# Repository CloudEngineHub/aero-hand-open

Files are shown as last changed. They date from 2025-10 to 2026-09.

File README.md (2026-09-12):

Aero Hand Overview

<p align="center">
  
  
  
  <!-- <a href="https://github.com/chestnut-robotics/aero-hand-open/issues"><img src="https://img.shields.io/github/issues/chestnut-robotics/aero-hand-open?color=yellow" alt="Issues"></a> -->
  
  
  
  
  
  
</p>

Aero Hand Open is an **open-source**, **tendon-driven** robotic hand designed and developed by Chestnut Robotics (formerly TetherIA) for dexterous manipulation research. Unlike expensive proprietary solutions, this hand focuses on **simplicity**, **reliability**, and **accessibility** by using standard 3D printing and off-the-shelf electronic components.

Each joint is optimized for mechanical efficiency through tendon actuation, enabling smooth and natural motion while maintaining a **lightweight** and **compact** design, making it perfect for research labs, educational institutions, and robotics enthusiasts who need an **affordable** yet **capable** manipulation platform.

> **📄 Paper:** [Aero Hand Open: A Simulation-Ready Tendon-Driven Hand for Dexterous Manipulation Learning](https://arxiv.org/abs/2608.28578) (arXiv:2608.28578)   
> **📚 Learn More:** https://chestnut-robotics.github.io/aero-hand-open/   
> **🛒 Shop:** https://shop.tetheria.ai/

# Aero Hand Open features
- 7 DoFs robotic hand with 5 fingers (16 joints in total)
- Tendon-driven architecture for smooth and natural motion
- Fully 3D-printed structure, modular and easy to assemble
- Lightweight design — **389 g**
- Affordable — complete kit for **$314 USD**
- Open-source hardware and firmware
- Independent Python SDK, and compatible with ESP32 and ROS2 systems

# Table of Contents
- [Aero Hand Open features](#aero-hand-open-features)
- [Overview](#overview)
- [Resources](#resources)
  - [Bill of Materials (BOM)](#bill-of-materials-bom)
  - [CAD Files and 3D Models](#cad-files-and-3d-models)
  - [Assembly Guide](#assembly-guide)
  - [PCB Design](#pcb-design)
  - [Hardware Setup](#hardware-setup)
  - [Software SDK](#software-sdk)
  - [ROS2 and Teleoperation](#ros2-and-teleoperation)
  - [Simulation](#simulation)
  - [Reinforcement Learning](#reinforcement-learning-tools)
- [Getting help](#Getting-help)
- [Citation](#citation)
- [License — TL;DR](#license--tldr)
- [Disclaimer](#disclaimer)
- [Project Updates & Community](#project-updates--community)
  - [Updates History](#updates-history)
  - [FAQ](#faq)
  - [Contact](#contact)

# Overview

Overview1

Overview1

Overview1

Overview1

Overview1

Overview1

Overview1

# Resources
## Bill of Materials (BOM)
The complete list of components required to build Aero Hand Open can be found here:

 [👉 Aero Hand Open – Bill of Materials](./hardware/Assembly/BOM.csv)

This document includes all mechanical, electronic, and printed parts — such as motors, tendons, bearings, fasteners, and 3D-printed components.

Each item is listed with its part number, vendor, quantity, and estimated cost to help you easily source or substitute parts.

## CAD Files and 3D Models
STEP files and one click print files can be found here:

[👉 Aero Hand Open – CAD](./hardware/CAD/).

[👉 Aero Hand Open – Onshape Link](https://cad.onshape.com/documents/afc7e0ca7eb6d412ec8771f8/w/bc4d7e45e17e23d622d2bad2/e/c711982b7882da925263fb55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)

All parts are printed on a Bambu X1C, 0.4mm nozzle, 0.2mm layer height, tree support enabled, select support on build plate only checkbox. We recommend keeping the same print orientation and settings. The print orientation will minimize supports and optimize surface tolerances/smoothness for interfacing components.

## Assembly Guide
The step-by-step assembly instructions for Aero Hand Open are provided in the following document:

[👉 Aero Hand Open – Assembly Guide](https://docs.tetheria.ai/docs/assembly)

This guide covers the entire build process, from mounting the actuators to routing the tendons and connecting the electronics. Each finger module can be assembled independently and attached to the palm afterward, allowing easier maintenance and quick replacement.

## PCB Design
All design files - including Gerber files, KiCad project files, BOM, and CPL - are available in [PCB folder](./hardware/PCB/).

Referring to [PCB doc](https://docs.tetheria.ai/docs/pcb) for more technical details.

## Hardware Setup

Please refer to [hardware_setup](https://docs.tetheria.ai/docs/hardware_setup) doc 

## Software SDK
Please refer to [`sdk/README.md`](sdk/README.md) and [sdk](https://docs.tetheria.ai/docs/sdk) doc

### Sequencing Demo
The Sequencing Demo demonstrates how different finger motions can be combined into continuous, pre-defined sequences.

This script enables users to perform complex gestures — such as pinching, opening the palm, or making a peace sign — by automatically coordinating joint movements in a timed sequence.

You can find the example code in the SDK example folder. 

👉 [`sdk/examples/`](sdk/examples)

Once the SDK is installed and the serial port has been configured, you can run any of the example scripts directly using Python as follows:

```bash
python run_sequence.py
```
[🎥 Watch the demo](assets/sequence_square.mp4)

## ROS2 and Teleoperation
The Aero Hand Open integrates seamlessly with ROS2 **humble** for advanced robotics applications.

Refer to the [ROS2](https://docs.tetheria.ai/docs/ros2) doc and [`ros2/`](./ros2/) folder for complete setup instructions and source code.

## Simulation

We provide high-fidelity simulation models for the **Aero Hand Open**.

**Currently Supported**
- **MuJoCo**

Support for additional simulation platforms is under active development and will be released in future updates.  
Refer to the [RL and Sim](https://docs.tetheria.ai/docs/hand_sim) documentation and the [`sim_rl/simulation/`](./sim_rl/simulation/) directory for detailed explanations and model files.

## Reinforcement Learning Tools

We offer reinforcement learning tools built on top of state-of-the-art frameworks such as **mujoco_playground**, enabling users to train custom policies for the Aero Hand Open with minimal effort.

Refer to the [RL and Sim](https://docs.tetheria.ai/docs/hand_sim) documentation and the [`sim_rl/mujoco_playground/`](./sim_rl/mujoco_playground/) directory for full setup instructions and training procedures.  
An example of deploying trained policies in ROS is also provided in the [`ros2/`](./ros2/) directory.

# Getting help

**GitHub Issues** – Bugs + feature requests only.

**GitHub Discussions** –
- Build / electronics / mechanical help
- SDK / ROS2 / sim/RL "how do I…"
- Design proposals and feedback

**Discord** –
- Quick questions, live debugging, voice/screen‑share
- Social chat, lab intros, "I printed my first hand!"
- Live events and office hours

# Citation

If you use Aero Hand Open in your research, please cite our paper:

> Nan Wang, Mohit Yadav, Jonathan Wulff, Aidan Rosenbaum, Kezhou Chen, Yuvan Sharma, Xu Dong, Yiwei Tao.
> **Aero Hand Open: A Simulation-Ready Tendon-Driven Hand for Dexterous Manipulation Learning.** arXiv:2608.28578, 2026.
> [📄 arXiv](https://arxiv.org/abs/2608.28578) · [PDF](https://arxiv.org/pdf/2608.28578)

```bibtex
@article{wang2026aerohandopen,
  title   = {Aero Hand Open: A Simulation-Ready Tendon-Driven Hand for Dexterous Manipulation Learning},
  author  = {Wang, Nan and Yadav, Mohit and Wulff, Jonathan and Rosenbaum, Aidan and
             Chen, Kezhou and Sharma, Yuvan and Dong, Xu and Tao, Yiwei},
  journal = {arXiv preprint arXiv:2608.28578},
  year    = {2026},
  url     = {https://arxiv.org/abs/2608.28578}
}
```

# License — TL;DR



- You **can** integrate Aero Hand units you purchase from Chestnut Robotics into **commercial robots and products** you sell.
- **Software (firmware & SDK):** Apache-2.0 — commercial use OK (with notices).
- **Design files (CAD/STEP/STL, drawings, BOM, docs):** CC BY‑NC‑SA 4.0 — **non‑commercial** only; derivatives must use the same license with attribution.
- Want to **manufacture/print parts** or **make your own hands** from our design files for commercial use (spares, kits, or clones)? → **Commercial manufacturing license required**.
- **Commercial licensing & volume buys:** see **LICENSE.md** (or email us at contact@chestnut.bot).

See [**LICENSE.md**](LICENSE.md) for definitions, examples, and contact details.

© 2025 Chestnut Robotics, Inc. (formerly TetherIA, Inc.) All rights reserved.

# Disclaimer
Aero Hand Open is an open-source research prototype intended for educational and experimental purposes only.

While every effort has been made to ensure build accuracy and functionality, this design has not been validated for prolonged or heavy-duty use.

Users should exercise caution when assembling, operating, or modifying this device. Chestnut Robotics, Inc. and its contributors shall not be held liable for any personal injury, property damage, or other losses resulting from the use, misuse, or modification of this design. By using this project, you acknowledge and accept full responsibility for any associated risks.

Important Notes:
- 3D-printed parts may exhibit tolerance variations depending on printer and material settings.
- The tendon-driven mechanism requires regular tension adjustment to maintain consistent motion.
- Overloading the joints or applying excessive torque may cause mechanical deformation or servo damage.
- This project is provided as is, without any warranty or guarantee of fitness for a particular purpose.

We encourage the community to share improvements, feedback, and modifications through pull requests or GitHub discussions.

Your contributions will help make Aero Hand Open more reliable and versatile for the entire robotics community.

# Project Updates & Community
## Updates History
See [RELEASE_NOTES.md](RELEASE_NOTES.md) for details.

## FAQ
Q1: Can I modify and redistribute the Aero Hand Open design?

A: Yes, as long as it complies with the CC BY-NC-SA 4.0 license (non-commercial, attribution required, share alike).

Q2: What 3D printer and material do you recommend?

A: Any FDM printer with a ≥200×200 mm bed. PLA works best for strength and dimensional accuracy.

More questions please refer to our [online documentation](https://docs.tetheria.ai/docs/hardware_faq) 

## Contact
For questions, feedback, or collaboration inquiries, please reach out to us through the following channels:

 🛒 Shop: [Aero Hand Open – Chestnut Robotics Store](https://shop.tetheria.ai/) 

 📚 Docs: [Aero Hand Open Docs](https://docs.tetheria.ai/)

 📧 Email: support@chestnut.bot

 🌐 Website: [chestnut.bot](https://chestnut.bot)

 🐙 GitHub: [chestnut-robotics](https://github.com/chestnut-robotics)

 💬 Discord: [Chestnut Robotics Discord](http://discord.gg/ZQKWK7NebQ)

  🐦 X/Twitter: [Chestnut Robotics on X](https://x.com/ChestnutRobotic)

  📺 YouTube: [Chestnut Robotics on YouTube](https://www.youtube.com/@TetherIA_ai)

  💼 LinkedIn: [Chestnut Robotics on LinkedIn](https://www.linkedin.com/company/tetheria/)

We welcome discussions, contributions, and new ideas from the community.

If you have improvements to the design, firmware, or control software, feel free to open a Pull Request or start a Discussion on GitHub.

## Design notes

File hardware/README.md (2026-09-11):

**License:** [CC BY-NC-SA 4.0](https://creativecommons.org/licenses/by-nc-sa/4.0/) © 2025 Chestnut Robotics

[**Mechanical**](https://docs.tetheria.ai/docs/mechanical)

[**Assembly**](https://docs.tetheria.ai/docs/assembly)

[**Hardware Setup**](https://docs.tetheria.ai/docs/hardware_setup)

[**PCB**](https://docs.tetheria.ai/docs/pcb)

[**Firmware**](https://docs.tetheria.ai/docs/firmware)

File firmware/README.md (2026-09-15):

<p align="center">
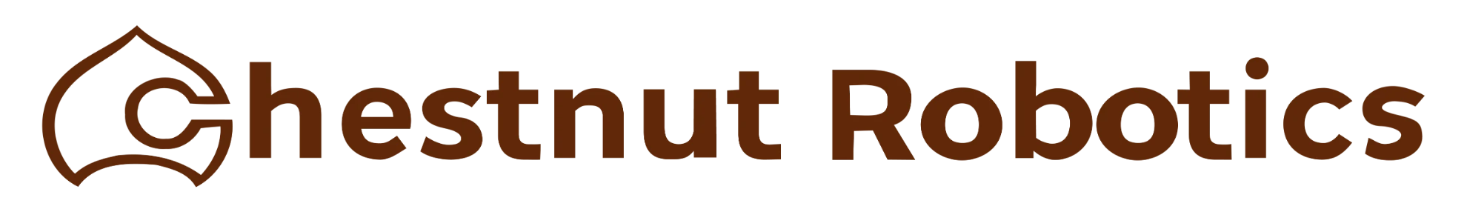
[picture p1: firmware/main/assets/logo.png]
Aero Hand Open by Chestnut Robotics
  
  <br/><br/>
</p>

# Aero Hand Open Firmware v0.1.0 — README

A reference guide for building, flashing, using, and extending the **Aero Hand Open** firmware that runs on an ESP32‑S3 (Seeed Studio XIAO ESP32S3) and drives Feetech smart servos - Feetech HLS3606M.

**Note:** If you do not need advanced control over the actuator, you only need the `.bin` file from this repository. You can download the bin files from the `main/bin` folder , and use the GUI to upload them to your device. We recommend using the [aero-open-sdk](https://github.com/chestnut-robotics/aero-hand-open/tree/main/sdk) to upload the firmware by running the `aero-open-gui`.

---

## Table of Contents
- [1) Overview](#1-overview)
- [2) Repository Layout](#2-repository-layout)
- [3) Hardware & Software Requirements](#3-hardware--software-requirements)
- [4) Quick Start](#4-quick-start)
- [5) Firmware Architecture](#5-firmware-architecture)
- [6) Selecting LEFT vs RIGHT Hand at Build Time](#6-selecting-left-vs-right-hand-at-build-time)
- [7) Serial Protocol](#7-serial-protocol)
- [8) Homing Behavior](#8-homing-behavior)
- [9) Extending the Firmware with a New Command](#9-extending-the-firmware-with-a-new-command)
- [10) Code Reference (quick lookup)](#10-code-reference-quick-lookup)
- [11) Safety & Best Practices](#11-safety--best-practices)
- [12) Troubleshooting](#12-troubleshooting)
- [13) Contribution](#13-contribution)
- [14) License](#14-license)
- [15) Support](#15-Support)

---

## 1) Overview

The firmware exposes a compact **fixed 16‑byte binary serial protocol** so a host PC can command finger positions and query telemetry while the device handles **homing**, calibration, and basic safety on‑board.

**Major components**
- **`firmware_v0.1.0.ino`** — Main sketch: hardware init, serial command parser, periodic tasks, and command handlers.
- **`HandConfig.h`** — **Defines LEFT_HAND or RIGHT_HAND** (build‑time) to select the correct baseline calibration and channel directions.
- **`Homing.h` / `Homing.cpp`** — Implements the **homing** routine (`HOMING_start()` / `HOMING_isBusy()`), plus baseline tables and helpers.

**Servos / channels** (7):
1. Thumb CMC Abduction
2. Thumb CMC Flexion
3. Thumb Tendon (thumb curl/tendon drive)
4. Index
5. Middle
6. Ring
7. Pinky

---

## 2) Repository Layout

```
/main
  ├─ firmware_v0.1.0.ino          # main sketch
  ├─ HandConfig.h                 # LEFT_HAND / RIGHT_HAND selection
  ├─ Homing.h                     # homing API + ServoData type
  ├─ Homing.cpp                   # homing implementation + baselines
  └─ (libraries as needed)
```

---

## 3) Hardware & Software 

- **MCU**: Seeed Studio XIAO ESP32‑S3 (8 MB flash recommended)
- **Servos**: Feetech HLS3606M (IDs mapped to the 7 joints)
- **Power**: Power Servo rail at 6 with adequate current (Max Current up to 10A) , separate from USB 5 V
- **Tools**: [Arduino IDE](https://www.arduino.cc/en/software/) or PlatformIO.

---

## 4) Quick Start

### A. Select LEFT or RIGHT hand
In `HandConfig.h`, **define exactly one** of the following macros, or pass a build flag (see §6):
```c++
// #define LEFT_HAND
#define RIGHT_HAND
```

The choice selects the correct baseline calibration table at build time.

### B. Build & Flash
- **PlatformIO**: On your Visual Studio Code, Once you install the platformIO, Restart your Visual studio Code. You will now see a icon on the left for PlatformIO as below.


Once You Reach here, You can press on create a new project . Once you click , It will ask you to enter the Project name and settings, Feel free to choose your desired location and project name,But keep Framework as Arduino and Board as Seeed Studio XIAO ESP32S3.



Now it will open the folder with a `platformio.ini` file. You might need to add a location where you have the FTServo library.  You can use build_flags to build it for the right or left hand. You need to copy paste over the ``firmware_v0.1.0.ino`` file in the ``main.cpp`` and you also need the header and cpp files under src directory as in the below given image.



Now, You again need to go back to that build and upload page by pressing the PlatformIO icon. Here you can see an upload , Once you press the upload button, It should compile your files and upload it.


On successful upload, You will see some logs in your terminal window like in the image below.


- **Arduino IDE**: open `firmware_v0.1.0.ino`, set Board to *XIAO ESP32S3*, then **Upload**.  
  **Note:** If you are using the Arduino IDE for the first time, you may need to install the ESP32 board support. Go to the Board Manager by pressing Ctrl+Shift+B, then search for "esp32". Find "esp32 by Espressif Systems" and install it. After installation, change the board under the Tools menu and select "XIAO_ESP32S3" from the list.

  

  

### C. First Boot
1. Connect USB, open a serial monitor at the project baud rate (e.g., 1,000,000 or 115,200 as configured - default 921600).
2. On Pressing Reset, Using the Serial monitor make sure that you receive OK from all 7 Servos.

---

## 5) Firmware Architecture

### 5.1 Data structures
- **`ServoData`**: per‑channel configuration `{grasp_count, extend_count, servo_direction}` used to map 16‑bit host commands into per‑servo raw counts (0..4095).
- **Baselines**: compile‑time constants for LEFT and RIGHT hands (7 entries each). A runtime working copy `sd[7]` is initialized from whichever baseline the build selects.

### 5.2 Homing module
- **`HOMING_start()`**: runs the homing routine for all 7 servos.
- **`HOMING_isBusy()`**: returns true while homing is in progress.
- **`resetSdToBaseline()`**: copies the correct baseline into the working array before homing.

### 5.3 Main loop
The main loop performs:
- USB serial polling
- Fast‑path command decode (see §7)
- Optional periodic telemetry sampling and printing

---

## 6) Selecting LEFT vs RIGHT Hand at Build Time

You can switch hands either by editing `HandConfig.h` **or** using build flags.

- **PlatformIO** (`platformio.ini`):
- lib_extra_dirs point to the location where you might need the [FTServo_libraries](https://github.com/ftservo/FTServo_Arduino/tree/main).
- You need to comment both macros of #define LEFT_HAND and #define RIGHT_HAND in ``HandConfig.h``.
- build_flags will help you to build it for the right hand.
  ```ini
  [env:seeed_xiao_esp32s3]
  platform = espressif32
  board = seeed_xiao_esp32s3
  framework = arduino
  lib_extra_dirs = ~/Documents/Arduino/libraries
  build_flags= -DRIGHT_HAND
  ```

- **Arduino IDE**: temporarily uncomment the macro in `HandConfig.h`.

> **Tip:** Keep the default checked into version control (usually `RIGHT_HAND`) and apply overrides via build flags in CI or per‑developer settings.

---

## 7) Serial Protocol

### 7.1 Frame format

### Frame Structure (TX and RX)
| Bytes | Field | Description |
|---|---|---|
| 0 | **Opcode** | Command / response code (e.g., `0x01` for HOMING, `0x03` for TRIM). |
| 1 | **Filler** | Always `0x00` (reserved for future use). |
| 2..15 | **Payload** | 14-byte payload. May contain parameters (channels, degrees, IDs, etc.) or be all zeros in acknowledgments. |

- **All commands from PC → firmware are 16 bytes.**  
- **All responses (ACKs) from firmware → PC are also 16 bytes.**

| Opcode | Name | Direction | Payload (host→device unless noted) | Response (device→host) |
| -----: | --- | --- | --- | --- |
| `0x01` | `HOMING` | H→D | 14 × `0x00` | `[0x01,0x00, 14×0x00]` when complete |
| `0x02` | `SET_ID` | H→D | `new_id(u16)`, `current_limit(u16)`, rest zeros | `[0x02,0x00, oldId(u16), newId(u16), curLim(u16), rest 0]` |
| `0x03` | `TRIM` | H→D | `channel(u16:0..6)`, `degrees(i16: ±360)`, rest zeros | `[0x03,0x00, channel(u16), extendRaw(u16), presentRaw(u16), status(u16), version(u16), rest 0]` |
| `0x04` | `CALIBRATE_MID` | H→D | `channel(u16:0..6)`, rest zeros | `[0x04,0x00, channel(u16), presentRaw(u16), presentU16(u16), status(u16), version(u16), rest 0]` |
| `0x11` | `CTRL_POS` | H→D | **7×** `u16` (channels 0..6). Range `0..65535` maps to **extend→grasp** span per channel. | *(none)* |
| `0x12` | `CTRL_TOR` | H→D | Set torque for all servos (7×u16) | *(none)* |
| `0x22` | `GET_POS`  | H↔D | 14×`0x00` | **7×** `u16` raw positions (counts 0..4095) |
| `0x23` | `GET_VEL`  | H↔D | 14×`0x00` | **7×** `u16` raw velocities |
| `0x24` | `GET_CURR` | H↔D | 14×`0x00` | **7×** `u16` currents |
| `0x25` | `GET_TEMP` | H↔D | 14×`0x00` | **7×** `u16` temperatures (°C or raw, per build) |
| `0x31` | `SET_SPE`  | H→D | `id(u16)`, `speed(u16)`, rest zeros | ACK: id, speed |
| `0x32` | `SET_TOR`  | H→D | `id(u16)`, `torque(u16)`, rest zeros | ACK: id, torque |

Control Modes Note: 
> **Recommendation:** We recommend using position control for typical grasping tasks. Advanced users may use torque control mode, but only when the hand is in a position to grab an object. At higher torque values, if any servo exceeds an internal temperature of 80°C, it may temporarily ignore commands as a safety measure until it cools down.
> **Note:** Torque control is currently implemented in one direction only: from fully open to fully close.

**7.2 Channel Map (0..6)**

0: Thumb CMC Abduction
1: Thumb CMC Flexion
2: Thumb Tendon (curl)
3: Index Finger
4: Middle Finger
5: Ring Finger
6: Pinky Finger 

**7.3 Position Mapping (host 16-bit → servo raw count)**

For each channel i, map host value u16[i] ∈ [0..65535] into raw servo counts using per-channel calibration:

span   = grasp_count[i] - extend_count[i]          // can be ±
raw32  = extend_count[i] + (u16[i] * span) / 65535
raw    = clamp(raw32, 0, 4095)

Direction is handled via servo_direction. Final writes use bus-batched SyncWrite (e.g., SyncWritePosEx) for all 7 servos.

**7.4 Persistence, Homing & Timing**

TRIM updates the extend endpoint for one channel and saves it in NVS (persists across reboots). Its ACK also reports the saved `extendRaw` and the actuator's current `presentRaw` position.

### 7.4.1 Manual middle calibration

`CALIBRATE_MID` calibrates the selected actuator's current physical position as its middle position. This is useful when tendon length, pretension, or spool winding places the useful finger travel outside the default single-turn window. After middle calibration, use TRIM to align the extend endpoint.

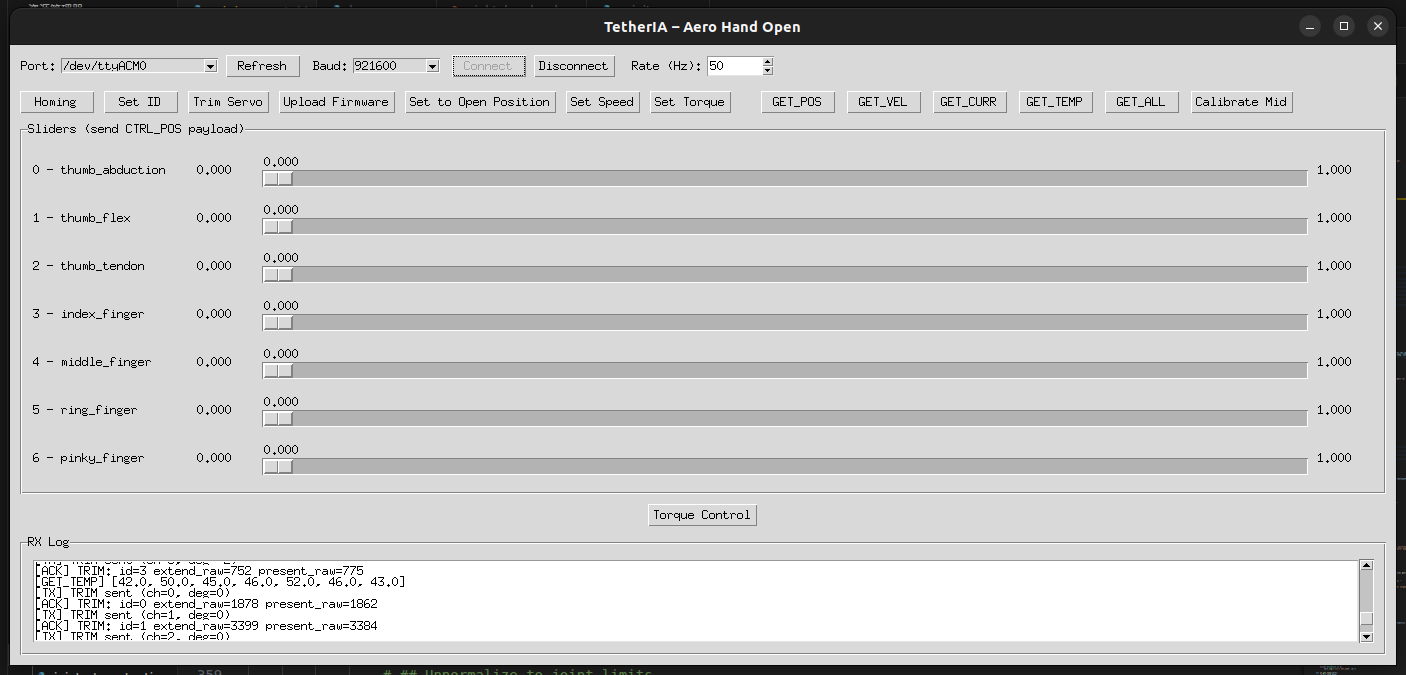
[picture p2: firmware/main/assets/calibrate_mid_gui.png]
Calibrate Mid GUI


A real assembly can have a different tendon/spool winding direction or initial wrap than the default homing assumption:

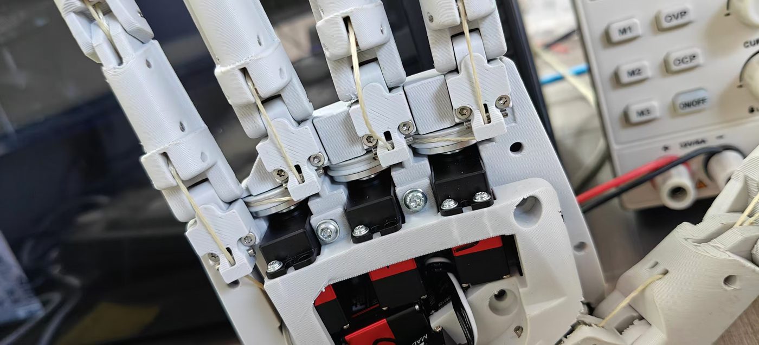
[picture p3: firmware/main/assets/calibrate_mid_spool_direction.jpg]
Tendon spool direction example


Safe procedure:

1. Set a low speed and torque limit for the selected channel.
2. Use the slider to place the actuator at the desired physical reference position.
3. Press **Calibrate Mid**, select the channel, and confirm the warning.
4. Check that the returned `presentRaw` is near the actuator midpoint (approximately 2048).
5. Use **Trim Servo** to adjust the extend endpoint; its ACK prints both `extendRaw` and `presentRaw`.

The slider remains unchanged during calibration. When position streaming resumes, the actuator may move because the same slider target is interpreted in the new coordinate system. Running HOMING later recalibrates the actuator offset again and can replace this manual middle calibration.

HOMING:

Loads baseline tables (LEFT/RIGHT per build flag).

Drives each joint to contact (current-based) to re-establish the open/extend reference.

Blocking: Other commands are ignored until homing finishes and the ACK is issued.

Typical full sequence can take up to ~25 seconds per channel (mechanics-dependent).

GUI “Set to Extend” is a function that sends CTRL_POS with all channels at extend (open). It’s not a separate opcode.

**7.5 Example Frames**

Homing (host→device, then device→host ACK):

```Payload
TX: 01 00 00 00 00 00 00 00 00 00 00 00 00 00 00 00
RX: 01 00 00 00 00 00 00 00 00 00 00 00 00 00 00 00
```

Set ID to 0x0003, current limit 1023 (0x03FF):
```Payload
TX: 02 00 03 00 FF 03 00 00 00 00 00 00 00 00 00 00
RX: 02 00 oldId_lo oldId_hi 03 00 FF 03 00 00 00 00 00 00 00 00
```

Trim channel 3 by −100° (0xFF9C):
```Payload
TX: 03 00 03 00 9C FF 00 00 00 00 00 00 00 00 00 00
RX: 03 00 03 00 ext_lo ext_hi pos_lo pos_hi 00 00 01 00 00 00 00 00
```

CTRL_POS (7 channels). Example: all open (0):
```Payload
TX: 11 00 00 00 00 00 00 00 00 00 00 00 00 00 00 00
(no ACK)
```

GET_TEMP → returns 7×u16 temps:
``` Payload
TX: 25 00 00 00 00 00 00 00 00 00 00 00 00 00 00 00
RX: 25 00 t0_lo t0_hi t1_lo t1_hi ... t6_lo t6_hi
```

**7.6 Bus Access & Robustness**

All sync-read/write paths use a semaphore (e.g., gBusMux) for bus locking to avoid collisions.

Unknown/invalid opcodes are safely ignored to preserve frame alignment.

During HOMING, handlers ignore incoming writes; queue them on the host side.

**7.7 Practical Tips**

Use modest rates (e.g., 50 Hz) for CTRL_POS during validation.

Ensure the servo supply can deliver peak current without droop.

If motion looks inverted, swap extend_count/grasp_count or adjust servo_direction.

To revert large trims, re-run HOMING to restore baselines.

---

## 8) Homing Behavior

The homing routine:
1. Loads the correct baseline via `resetSdToBaseline()`.
2. For each servo, **slowly drives towards a mechanical stop** while monitoring current (a “zero with current” approach).
3. Calibrates offset at contact, performs a small back‑off/settling motion, and finally moves to a defined **extend** posture for consistency across boots.

Timing, current limits, and per‑servo special cases (e.g., thumb tendon) are enforced internally to reduce stress on the mechanism.

> You can safely call `HOMING_start()` at any time from the serial command handler. While homing, ignore position writes or buffer them on the host side.

---

## 9) Extending the Firmware with a New Command

When you want to add a new feature (e.g., LED blink, torque enable/disable, save trim, etc.), follow this pattern:

### Step 1 — Add a new **control byte** (opcode)
At the top of `firmware_v0.1.0.ino`, define a unique `#define` or `static const uint8_t` value not already in use.
```c++
// Example: a simple LED or debug action
static const uint8_t OP_BLINK = 0x42;   // choose a free byte
```

### Step 2 — Implement a handler function
Keep the switch‑case light by moving logic into a small function.
```c++
static void handleBlink(uint8_t count) {
  for (uint8_t i = 0; i < count; ++i) {
    digitalWrite(LED_BUILTIN, HIGH);
    delay(80);
    digitalWrite(LED_BUILTIN, LOW);
    delay(80);
  }
}
```

### Step 3 — Add a `case` in the serial parser
Consume the payload as per use and call the function as per your handler.
```c++
case OP_BLINK: {
  uint8_t count = buf[1];                 // interpret first payload byte
  handleBlink(count);
  break;
}
```

### Step 4 — (Optional) Add a response
If the command should acknowledge or return data, write a 16‑byte response using the same framing convention (byte 0 = response opcode, byte 1 = 0x00, bytes 2..15 = payload).

### Step 5 — Update host tools
If you plan to use our aero-open-hand sdk then you might need to add that functionality under aero_hand.py file.

> **Naming tip:** Use `OP_*` for commands initiated by the host and `RX_*` or `OP_RSP_*` for device responses to avoid confusion.

---

## 10) Code Reference (quick lookup)

### Homing API
```c++
bool HOMING_isBusy();
void HOMING_start();
void resetSdToBaseline();
```

### Servo configuration
```c++
struct ServoData {     // one per channel
  uint16_t grasp_count;    // closed endpoint (raw 0..4095)
  uint16_t extend_count;   // open endpoint  (raw 0..4095)
  int8_t   servo_direction; // +1 or -1 direction convention
};
```

### Build‑time hand selection
```c++
// In HandConfig.h: define exactly one
// #define LEFT_HAND
// #define RIGHT_HAND
```

---

## 11) Safety & Best Practices
- Start with **low speeds/torque** when testing new code.
- Ensure the servo supply can deliver peak current without large droops.
- Keep cable lengths short and bus terminations clean; avoid ground loops.
- Avoid sending high‑rate position frames during homing.

---

## 12) Troubleshooting
- **Wrong hand geometry**: Verify your build flags (`-DLEFT_HAND` vs `-DRIGHT_HAND`).
- **Servos drive the wrong way**: Check `servo_direction` for the affected channel or swap extend/grasp counts.
- **Homing stalls**: Inspect current limits/timeouts; make sure mechanics move freely.
- **No serial activity**: Confirm port, baud rate, and that frames are exactly 16 bytes with the correct opcode.

---

## 13) Contribution
We welcome community contributions!

If you would like to improve the Firmware or add new features:

1. Fork and create a feature branch.
2. Add or modify opcodes and handlers as described in Section 9.
3. Include brief unit/bench tests where possible.
4. Commit your changes with clear messages.
5. Push your branch to your fork.
6. Open a PR with a summary and scope of changes.

---

## 14) License
This project is licensed under **Apache License 2.0**

---

## 15) Support 
If you encounter issues or have feature requests:
- Open a [GitHub Issue](https://github.com/chestnut-robotics/aero-hand-open/issues)
- Contact us at **contact@chestnut.bot**

---

<div align="center">
**Happy building!** Try something new, break things safely, and share what you learn.
If you find this project useful, please give it a star! ⭐

Built with ❤️ by Chestnut Robotics
</div>

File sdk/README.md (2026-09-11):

<p align="center">
  Aero Hand Open by Chestnut Robotics
  <br/><br/>
</p>

<div align="center">








</div>

<h2 align="center">
  <p>Aero Open SDK — Python interface for Chestnut Robotics’ Aero Hand Open</p>
</h2>

<div align="center">
  Aero Hand Demo Aero Hand in action
  <p><strong>Aero Open Hand</strong> is a 7-DoF tendon-driven robotic hand for dexterous manipulation and research.</p>
  <p>The SDK enables full control via Python. Perform homing, calibration, and precise motion control with ease.</p>
</div>

---

## ⚙️ Installation

The SDK is currently tested for Python 3.10 and above.

### 📦 Install via pip

```bash
pip install aero-open-sdk
```

### 🧩 Install from source (editable mode)

1. Clone the repository to your local machine:
   ```bash
   git clone https://github.com/chestnut-robotics/aero-hand-open.git
   ```

2. Navigate to the cloned repository directory:
   ```bash
   cd sdk
   ```

3. Install the package in editable mode:
   ```bash
   pip install -e .
   ```

---

## 🖥️ One-Time Setup

When setting up your hand for the first time, our setup GUI helps you configure motor IDs and test motor connections.

After installation, launch the Setup GUI with:

```bash
aero-open-gui
```

This provides an interactive interface to configure your hand.

---

## 🔌 Serial Port Setup

Aero Hand connects to the host PC via a serial (USB) interface.
To operate the SDK, you must specify the correct serial port for your device.

### 🐧 Linux

Most Linux systems assign the device path as `/dev/ttyACM0` or `/dev/ttyUSB0`. You can list connected serial devices with:

```bash
ls /dev/ttyACM* /dev/ttyUSB*
```

**💡 Persistent Device Path (Recommended)**

Device names like `/dev/ttyUSB0` can change each time you reconnect.

To get a persistent name, use the by-id symlink instead:

```bash
ls -l /dev/serial/by-id/
```

This will show you a list of connected serial devices with more descriptive names. Look for the one that corresponds to your Aero Hand. Which will look something like:
```bash
usb-Espressif_USB_JTAG_serial_debug_unit_D8:3B:DA:45:C8:1C-if00
```
Then initialize your hand using that path:
```python
from aero_open_sdk.aero_hand import AeroHand

aero_hand = AeroHand(
  port="/dev/serial/by-id/usb-Espressif_USB_JTAG_serial_debug_unit_D8:3B:DA:45:C8:1C-if00"
)
```
✅ This ensures your connection always points to the correct device, even if you unplug and replug the hand or change the USB port.

### 🪟 Windows
On Windows, the device will appear as a COM port like `COM3` or `COM4`. You can find the correct COM port by checking the Device Manager under "Ports (COM & LPT)".

You can then Initialize your hand with the detected COM port:
```python
from aero_open_sdk.aero_hand import AeroHand
aero_hand = AeroHand(port="COM3")
```
**💡 Making the COM Port Persistent**

Windows does not have a /by-id/ system like Linux, so the COM number can change if you plug the device into a different USB port.

To make it permanent, you can assign a fixed COM number:
1. Plug in the Aero Hand and open Device Manager.
2. Find it under Ports (COM & LPT).
3. Right-click → Properties → Port Settings → Advanced.
4. In COM Port Number, select an unused port (e.g., COM5).
5. Click OK to save.

You can now always use this COM port when initializing the SDK.

---

## 💡 Examples

To integrate the SDK into your own code, refer to the `examples` folder for sample files demonstrating basic usage.

---

## 🧰 Troubleshooting

### 1. Installation Fails (`pip install` error)

If installation fails, try the following steps:

- Check your Python version:

    Make sure you have Python 3.10 or higher installed.

- 🔧 Upgrade pip to the latest version:

    Our package requires an up-to-date version of pip.

    You can upgrade pip with:
    ```bash
    pip install --upgrade pip
    ```

On Windows, if you see error like "pip is not recognized", use the `py` launcher command instead:

    ```bash
    py -m pip install --upgrade pip
    ```

### 2. Path Mismatch on Windows

- You may not have the Python Scripts path added to your system PATH environment variable.

- To fix this, you can either:

  1. Add the Python Scripts directory (e.g., `C:\Users\<YourName>\AppData\Local\Programs\Python\Python310\Scripts`) to your system PATH.
  2. Or use the `py` launcher command to launch the GUI after installation:
      ```bash
      py -m aero_open_sdk
      ```
  3. Create a virtual environment and install the package there.
      ```bash
      python -m venv venv
      .\venv\Scripts\activate
      pip install aero-open-sdk
      aero-open-gui
      ```

### 3. Linux Troubleshooting: Serial Port Permission

If you see a permission error when connecting to the serial port (e.g., `/dev/ttyACM0`), do the following:

1. Find your username:
   ```sh
   whoami
   ```
2. Add your user to the `dialout` group (replace `yourusername` with the output from `whoami`):
   ```sh
   sudo usermod -a -G dialout yourusername
   ```
3. **Restart your system** (or log out and log back in).
4. After restart, open a terminal and run:
   ```sh
   groups
   ```
   You should see your username and `dialout` listed.
5. Try connecting to the serial port again in the GUI.

If you still see permission errors, check device permissions with:
```sh
ls -l /dev/ttyACM0
```
You may need to temporarily set permissions:
```sh
sudo chmod 666 /dev/ttyACM0
```

## 💬 Support

If you encounter issues or have feature requests:
- Open a [GitHub Issue](https://github.com/chestnut-robotics/aero-hand-open/tree/main/sdk/issues)
- Contact us at **contact@chestnut.bot**

---

## 🤝 Contribution

We welcome community contributions!

If you'd like to improve the SDK, fix bugs, or add new features:

1. Fork this repository.
2. Create a new branch for your changes.
    ```bash
    git checkout -b feature/your-feature-name
    ```

3. Commit your changes with clear messages.

4. Push your branch to your fork.

5. Open a Pull Request (PR) describing your updates.

---

## ⚖️ License

This project is licensed under the **Apache License 2.0**.

<div align="center">
If you find this project useful, please give it a star! ⭐

Built with ❤️ by Chestnut Robotics
</div>

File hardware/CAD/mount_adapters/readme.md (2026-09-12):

This folder contains all the adapters for Aero Hand Open designed for different robotic systems.

For instructions on connecting the adapter(s) with Aero Hand Open, please refer to [Adapter_Assembly_Instructions.pdf](Adapter_Assembly_Instructions.pdf).

## Available Adapters

**piper_arm_adapter.stp** - Designed for the [Piper Arm robotic system](https://global.agilex.ai/products/piper).

**threaded_mount_adapter.stl** - Designed to connect with a tripod mount, as demonstrated in our [previous X post](https://x.com/ChestnutRobotic/status/1987711095533113664?s=20).

**135degrees_adapter.stl** - A special adapter for the Piper robot arm that provides an optimal grasping angle. See [reference image](assets/135degrees_adapter.png).

**G1_Open_Unitree_Converter.stl** - adapter for [unitree G1 robot](https://www.unitree.com/g1)

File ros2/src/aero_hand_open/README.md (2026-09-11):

# 🤖 Aero Hand Open ROS 2 Node

The **Aero Hand Open Node** provides a ROS 2 interface for controlling Chestnut Robotics’ [Aero Hand](https://github.com/chestnut-robotics/aero-hand-open/tree/main/sdk) via the **Aero Hand SDK**.  
It allows controlling one or both hands simultaneously, exposing ROS 2 topics for both **joint-space** and **actuator-space** control.

## 🧩 Overview

This node acts as a bridge between ROS 2 and the Aero Hand hardware. It:
- Accepts commands for **joint angles** or **actuator positions**.
- Publishes real-time **actuator state feedback** (positions, speeds, currents, temperatures).
- Supports **single-hand** (right/left) or **dual-hand** operation.
- Uses parameters for serial ports, baud rate, and control mode.

## ⚙️ Running the Node

```bash
ros2 run aero_hand_open aero_hand_node
```

### Parameters

| Parameter | Type | Default | Description |
|---|---|---|---|
| `right_port` | `string` | `""` | Serial port for the right hand |
| `left_port` | `string` | `""` | Serial port for the left hand |
| `baudrate` | `int` | `921600` | Serial baud rate |
| `feedback_frequency` | `float` | `100.0` | Rate (Hz) to publish actuator feedback |
| `control_space` | `string` | `"joint"` | Control mode: `"joint"` or `"actuator"` |

Example run:
```bash
ros2 run aero_hand_open aero_hand_node --ros-args -p right_port:=/dev/ttyUSB0 -p left_port:=/dev/ttyUSB1 -p control_space:=joint
```

## 🛰️ ROS 2 Interfaces

### Subscribed Topics

| Topic | Message Type | Description |
|---|---|---|
| `right/joint_control` | `aero_hand_open_msgs/JointControl` | Right hand joint-angle commands (radians) |
| `left/joint_control` | `aero_hand_open_msgs/JointControl` | Left hand joint-angle commands (radians) |
| `right/actuator_control` | `aero_hand_open_msgs/ActuatorControl` | Right hand actuator-space commands |
| `left/actuator_control` | `aero_hand_open_msgs/ActuatorControl` | Left hand actuator-space commands |

> Only one control mode is active at a time, based on `control_space`.

### Published Topics

| Topic | Message Type | Description |
|---|---|---|
| `right/actuator_states` | `aero_hand_open_msgs/ActuatorStates` | Feedback for the right hand |
| `left/actuator_states` | `aero_hand_open_msgs/ActuatorStates` | Feedback for the left hand |

## 🧠 Behavior Summary

- **Initialization:**  
  Each hand is initialized if a valid serial port is provided.  
  The node throws an error if both `right_port` and `left_port` are empty.

- **Feedback:**  
  At the configured rate, the node publishes:
  - `actuations`
  - `actuator_speeds`
  - `actuator_currents`
  - `actuator_temperatures`

## 🧩 Dependencies

- **ROS 2 Humble** (or newer)
- **aero_open_sdk**
- **aero_hand_open_msgs**

Make sure the SDK is installed and accessible in your environment.

---

## ⚖️ License

This project is licensed under the **Apache License 2.0**.

---

<div align="center">
If you find this project useful, please give it a star! ⭐  

Built with ❤️ by <a href="https://chestnut.bot">Chestnut Robotics</a>
</div>

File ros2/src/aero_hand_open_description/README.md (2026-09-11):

# 🦾 Aero Hand Open Description — ROS 2 Package

The **Aero Hand Open Description** package provides the 3D model, URDF, and visualization configuration for **Chestnut Robotics’ Aero Hand Open** — a 7-DoF tendon-driven robotic hand designed for research and dexterous manipulation.  

---

## 🧩 Overview

This package contains:
- ✅ **URDF and meshes** for the right and left Aero Hand Open models.  
- ⚙️ **Launch files** for quick visualization in RViz.  

## ⚙️ Launch File: `display.launch.py`

This launch file loads the URDF model, publishes its joint states, and visualizes it in RViz.  

### Example Usage

```bash
ros2 launch aero_hand_open_description display.launch.py
```

## 🧪 Visualization Workflow

1. Launch RViz using this package:
   ```bash
   ros2 launch aero_hand_open_description display.launch.py
   ```
2. Move sliders in the **joint_state_publisher_gui** window to manipulate finger joints.
3. Observe the live visualization in RViz.

You can also remap the topic `/joint_states` or connect it to a live controller node (e.g., from `aero_hand_open` or `aero_hand_open_retargeting`).

---

## ⚖️ License

This project is licensed under the **Apache License 2.0**.

---

<div align="center">
If you find this project useful, please give it a star! ⭐  

Built with ❤️ by <a href="https://chestnut.bot">Chestnut Robotics</a>
</div>

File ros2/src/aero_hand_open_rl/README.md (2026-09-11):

# Deploying the Z-Rotation Policy for Aero Hand Open

This guide describes how to **deploy a trained Z-rotation policy** using reinforcement learning (RL), based on the task implemented in **[MuJoCo Playground](https://github.com/chestnut-robotics/mujoco_playground_pr)** for the **Aero Hand Open**.

---

## 🧩 Dependencies

The following repositories are required:

1. **[Aero-Hand-Open SDK](https://github.com/chestnut-robotics/aero-hand-open/tree/main/sdk)** — ships with this repository
2. **[Aero-Open-Firmware](https://github.com/chestnut-robotics/aero-hand-open/tree/main/firmware)** — prebuilt binaries ship with this repository
3. **[MuJoCo Playground](https://github.com/google-deepmind/mujoco_playground)**

---

## ⚙️ Install the Dependencies

### 1) Install Aero Hand SDK from source

The SDK lives in this repository under `sdk/`. Clone the repository and install it in
editable mode:

```bash
git clone https://github.com/chestnut-robotics/aero-hand-open.git
cd aero-hand-open/sdk
pip install -e .
```

For detailed installation instructions, see the [SDK guide](https://github.com/chestnut-robotics/aero-hand-open/tree/main/sdk).

---

### 2) Get the correct firmware binary

The prebuilt firmware binaries are shipped inside the repository you cloned in step 1, so
there is nothing extra to clone.

The Z-rotation policy was validated against firmware **v0.1.0**, archived at
[`firmware/main/bin/rl_z_rotation/`](https://github.com/chestnut-robotics/aero-hand-open/tree/main/firmware/main/bin/rl_z_rotation):

```text
firmware/main/bin/rl_z_rotation/firmware_v0.1.0_righthand.bin   # right hand
firmware/main/bin/rl_z_rotation/firmware_v0.1.0_lefthand.bin    # left hand
```

> **Note**
> `rl_z_rotation/` pins the exact build this guide was tested with. The binaries in the
> parent [`firmware/main/bin/`](https://github.com/chestnut-robotics/aero-hand-open/tree/main/firmware/main/bin)
> folder track firmware `main` and are newer even where the filename matches — see the
> [folder README](https://github.com/chestnut-robotics/aero-hand-open/tree/main/firmware/main/bin/rl_z_rotation)
> for details.

Note the path to the binary — you will select it from the GUI file browser in
[Run the Deployment → Flash the firmware](#1-flash-the-firmware).

---

### 3) Install MuJoCo Playground from source

Clone from our maintained fork:

```bash
git clone git@github.com:google-deepmind/mujoco_playground.git
cd mujoco_playground
```

Then follow the [installation guide](https://github.com/google-deepmind/mujoco_playground?tab=readme-ov-file#from-source).

---

## 🧱 3D-Printed Hardware

Deploying the Z-rotation policy on the **physical** hand requires two 3D-printed parts. The STEP (`.stp`) source files are provided in this package's `resource/` folder:

| File | Description |
| ---- | --- |
| [`60_60_60_block.stp`](resource/60_60_60_block.stp) | The 60 × 60 × 60 mm cube that the policy is trained to rotate about the Z-axis. Ideally printed to weigh **117 g** (tune infill/material so the printed cube matches this target mass). |
| [`mount.stp`](resource/mount.stp) | Mount/fixture used to hold the hand in place during deployment. |

Print both parts before running the deployment steps below.

---

## 🚀 Run the Deployment

### 1) Flash the firmware

1. Launch the GUI:
   ```bash
   aero-hand-gui
   ```
2. Locate the serial port connected to the hand.  
3. Click the **Upload Firmware** button.  
4. In the file browser, navigate to the pinned firmware folder of this repository:
   ```text
   aero-hand-open/firmware/main/bin/rl_z_rotation
   ```
   Select `firmware_v0.1.0_righthand.bin` (or `firmware_v0.1.0_lefthand.bin` for a left
   hand) and click **Open**.  
5. Close the GUI after flashing — keeping it open may interfere with serial communication.

---

### 2) Run the ROS 2 nodes

Enter the ROS 2 workspace, which also ships in this repository:

```bash
cd aero-hand-open/ros2
```

Build the required packages:

```bash
colcon build --select-packages aero_hand_open aero_hand_open_rl
```

Open two terminals.

**Terminal 1 — Start the communication node**
```bash
source install/setup.bash
ros2 run aero_hand_open aero_hand_node
```

**Terminal 2 — Run the policy node**
```bash
source install/setup.bash
ros2 run aero_hand_open_rl rl_z_rotation_deploy 
```

---

## 🧠 Notes

- A pretrained policy is already provided for direct deployment.  
- Ensure no other applications (e.g., GUI) are using the same serial port before running the ROS 2 nodes.

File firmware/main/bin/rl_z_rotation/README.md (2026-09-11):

# Firmware binaries for the RL Z-rotation policy

These binaries are the exact build the **Z-rotation RL policy** was validated against, kept
here so the [deployment guide](../../../../ros2/src/aero_hand_open_rl/README.md) does not
depend on access to the private `aero-open-firmware` repository.

## Provenance

Copied verbatim from `chestnut-robotics/aero-open-firmware`, `main/bin/`, at commit
`46bc858cf07f8c8858887ff11c5362b4078bc869`.

| File | Size (bytes) | SHA-256 |
| ---- | --- | --- |
| `firmware_v0.1.0_righthand.bin` | 349248 | `a112b5370e854c24d503c201fdea9e316a81b4d3839c45bbe4eca6beaa96786d` |
| `firmware_v0.1.0_lefthand.bin` | 349248 | `a112b5370e854c24d503c201fdea9e316a81b4d3839c45bbe4eca6beaa96786d` |

## ⚠️ These are not the latest v0.1.0 binaries

The files in the parent [`bin/`](..) folder track the firmware `main` branch and are newer,
even where the filename is the same. The v0.1.0 binaries were rebuilt twice after commit
`46bc858`:

- *Updated full speed after homing and handconfig for left or right hand* (upstream #11)
- *Added Set speed, Set torque and torque control mode* (upstream #12)

Use this folder only to reproduce the Z-rotation deployment; for anything else use the
maintained binaries in [`bin/`](..).

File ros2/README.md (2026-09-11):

<p align="center">
  Aero Hand Open by Chestnut Robotics
  <br/><br/>
</p>
 
<div align="center">




</div>

<h2 align="center">
  <p>Aero Hand Open ROS2 — ROS 2 packages for Chestnut Robotics’ Aero Hand Open</p>
</h2>

<div align="center">
  Aero Hand Demo Aero Hand in action
  <p><strong>Aero Hand Open</strong> is a 7-DoF tendon-driven robotic hand for dexterous manipulation and research.</p>
</div>

---

## ⚙️ Installation

We currently have tested the ROS2 package on **Ubuntu 22.04** with **ROS2 Humble Hawksbill**.

Follow the instructions in [INSTALL.md](INSTALL.md).

---

## 🚀 Next steps

- Start here: [Launch files overview](src/launch_files/readme.md)
- URDF/RViz visualization: `ros2 launch src/launch_files/display_launch/display.launch.py`
- Teleop launches:
  - Webcam: `src/launch_files/webcam_teleop_launch/readme.md`
  - Apple Vision Pro: `src/launch_files/vision_pro_teleop_launch/readme.md`
  - Manus glove: `src/launch_files/manus_teleop_launch/readme.md`

## 🧰 Troubleshooting
If something isn’t working, check:

- `INSTALL.md` for dependency setup
- `src/launch_files/*/readme.md` for per-launch requirements and arguments

## 💬 Support

If you encounter issues or have feature requests:
- Open a [GitHub Issue](https://github.com/chestnut-robotics/aero-open-ros2/issues)
- Contact us at **support@chestnut.bot**

---

## 🤝 Contribution

We welcome community contributions!

If you'd like to improve the SDK, fix bugs, or add new features:

1. Fork this repository.
2. Create a new branch for your changes.
    ```bash
    git checkout -b feature/your-feature-name
    ```

3. Commit your changes with clear messages.

4. Push your branch to your fork.

5. Open a Pull Request (PR) describing your updates.

---

## ⚖️ License

This project is licensed under the **Apache License 2.0**.

<div align="center">
If you find this project useful, please give it a star! ⭐

Built with ❤️ by Chestnut Robotics
</div>

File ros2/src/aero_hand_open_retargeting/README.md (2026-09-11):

# 🖐️ Aero Hand Open Retargeting — ROS 2 Package

The **Aero Hand Open Retargeting** package provides a ROS 2-based interface that enables real-time control of **Chestnut Robotics’ Aero Hand** using the **Manus gloves**.

## 🧩 Overview

This package:
- Subscribes to **Manus glove data** published via `manus_ros2`.
- Retargets (maps) the human hand joint angles to Aero Hand’s robotic joint structure.
- Publishes joint-space commands to the **Aero Hand Open Node** (`aero_hand_open`).

## 🚀 Launch File

The package includes a launch file that brings up the complete teleoperation pipeline:
- Manus glove data stream (`manus_ros2`)
- Retargeting node (`aero_hand_open_retargeting`)
- Aero Hand hardware node (`aero_hand_open`)

### Running the Teleop Stack
```bash
ros2 launch aero_hand_open_retargeting aero_hand_teleop.launch.py
```

## 🧰 Dependencies

- **ROS 2 Humble** (or newer)
- **manus_ros2**
- **aero_open_sdk**
- **aero_hand_open**
- **aero_hand_open_msgs**

Ensure all packages are built in your workspace before launching.

## ⚖️ License

This project is licensed under the **Apache License 2.0**.

---

<div align="center">
If you find this project useful, please give it a star! ⭐  

Built with ❤️ by <a href="https://chestnut.bot">Chestnut Robotics</a>
</div>

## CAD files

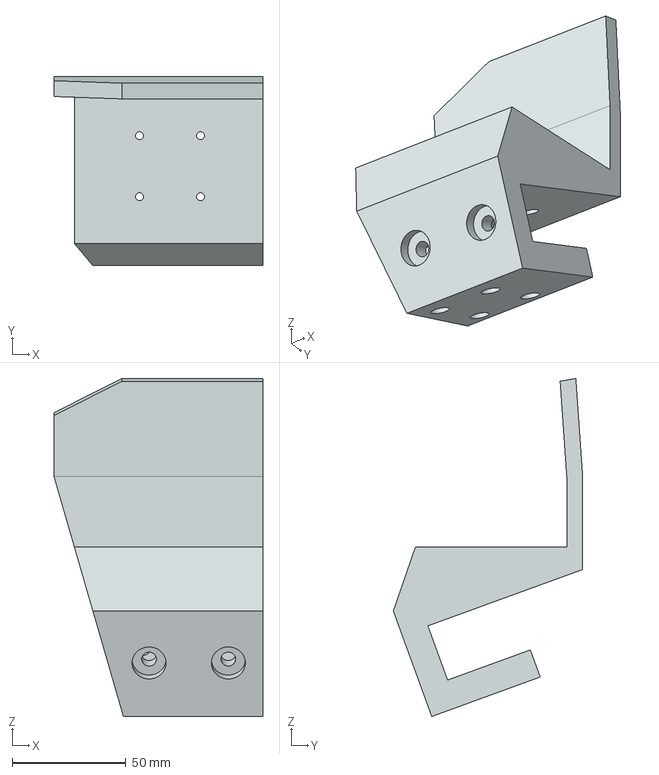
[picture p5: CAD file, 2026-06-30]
ros2/src/aero_hand_open_rl/resource/mount.stp
92.1 x 83.4 x 148.9 mm

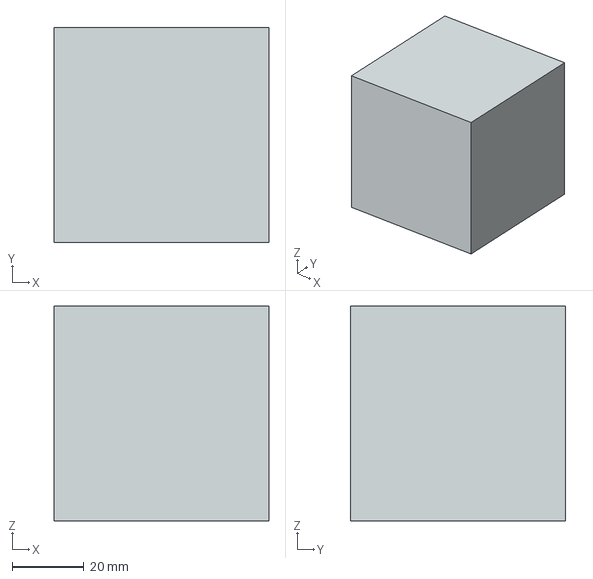
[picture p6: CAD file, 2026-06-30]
ros2/src/aero_hand_open_rl/resource/60_60_60_block.stp
60.0 x 60.0 x 60.0 mm

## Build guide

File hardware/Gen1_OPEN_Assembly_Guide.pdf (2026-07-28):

# Gen1 Open Source Hand Work Instruction by

2

# Useful Tools

### Tools:

1mm drill bit
2mm drill bit
2.1mm drill bit
Hand drill
Exacto Knife
Flash Cutters
File
Soldering Iron
Needle Nose Pliers
Phillips Driver
Torx Driver
Measuring Tape
Marker
Scissors

### Consumables:

Super Glue
Loctite (blue 496)

### Optional:

Silicone 2part
Hot Glue
Finger Tip Silicone Cover
Protoboard
22awg solid core wire
Reset tactile button
Solder Flux
Solder
Hot Glue Gun
Heat Insert Tip
Molex 3pin female Connector Palm Foam
Sandpaper

# 3D Printed Parts

PN | Name | QTY
01 | Finger Base | 4
02 | Finger MCP | 4
03 | Finger Proximal | 4
04 | Finger Medial | 4
05 | Finger Distal | 4
10 | Thumb CMC Base | 1
11 | Thumb MCP | 1
12 | Thumb Proximal | 1
13 | Thumb Distal | 1
3

PN | Name | QTY
14 | Servo Frame | 1
15 | Palm Front Frame | 1
16 | Palm Rear Frame | 1

4

14

16

15

Name | Part Number | QTY
Finger Base | 1 | 4
Finger MCP | 2 | 4
Finger Proximal | 3 | 4
Finger Medial | 4 | 4
Finger Distal | 5 | 4
Thumb CMC Base | 10 | 1
Thumb MCP | 11 | 1
Thumb Proximal | 12 | 1
Thumb Distal | 13 | 1
Servo Frame | 14 | 1
Palm Front Frame | 15 | 1
Palm Front Frame | 16 | 1

# 3D Print Cleanup

5

### Tools:

File
Sandpaper
Flash Cutter
Hand Drill (1mm, 2mm, 2.1mm)

# Debur 3D Printed Components

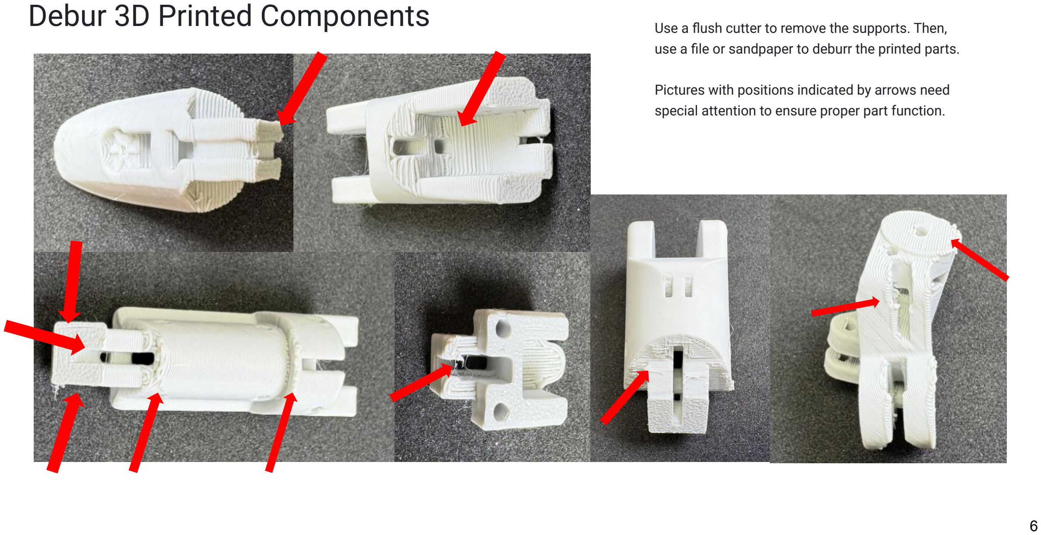
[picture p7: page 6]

6

Use a flush cutter to remove the supports. Then, use a file or sandpaper to deburr the printed parts.

Pictures with positions indicated by arrows need special attention to ensure proper part function.

7

8

### 1. Drill out holes in finger joints for all four fingers

### 2.0 mm

### 2.1 mm

### 1.0 mm

9

### 2.0 mm

### 2.1 mm

### 1.0 mm

# Drill

### 1. Drill out holes in thumb joints

Note: All holes are through holes unless otherwise stated

Not through
hole

Not through
hole

Name | ServoID # | QTY | Total Length (mm, from knot) | Marked Length (mm from spool exit)
Finger Pull Cable | 3,4,5 | 3 | 300 | 140
Pinky Pull Cable | 6 | 1 | 300 | 150
Finger Coupling Cable | NA | 4 | 300 | None
Thumb CMC Flex Cable | 1 | 1 | 300 | 90
Thumb Pull Cable | 2 | 1 | 300 | 150
Thumb Coupling Cable | NA | 1 | 300 | None

# Cable Pre-assembly

10

### Tools:

Scissors
Measuring Tape

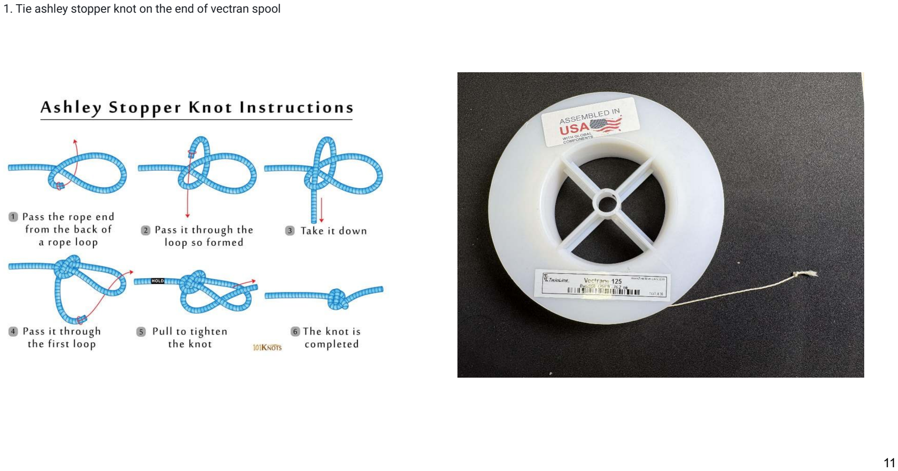
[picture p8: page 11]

### 1. Tie ashley stopper knot on the end of vectran spool

11

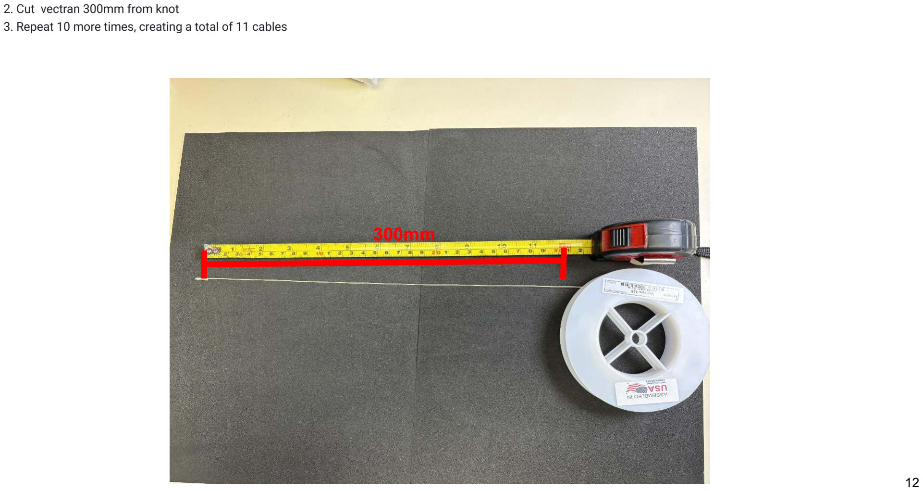
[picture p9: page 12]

### 2. Cut vectran 300mm from knot 3. Repeat 10 more times, creating a total of 11 cables

12

300mm

### 4. Trim the tail of the ashley stopper knot to <5mm

for all cables

13

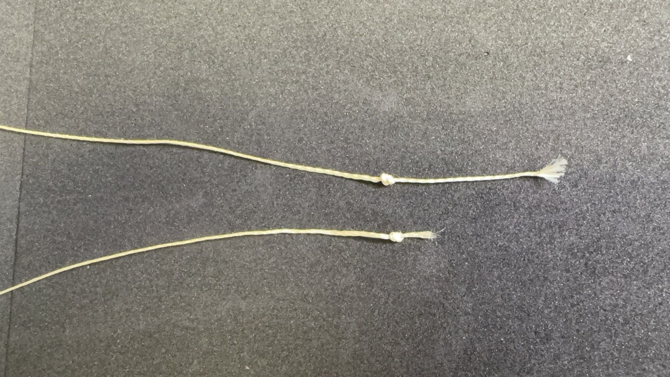
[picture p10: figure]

# Finger Assembly

14

### Tools:

Threading Tool
Pliers
Torx Driver
Name | Part Number | QTY
Finger Base | 1 | 4
Finger MCP | 2 | 4
Finger Proximal | 3 | 4
Finger Medial | 4 | 4
Finger Coupling Cable | 26 | 4
UNDERSIZED 2x10 Pin | 32 | 16
2x5x2.5 bearing | 30 | 16
1x10 Pin | 31 | 12
M2x6 Flanged Torx Self Tapping Screw | 38 | 4
Finger Proximal/MCP Return Spring | 22 | 4
Finger Distal/Medial and Thumb Proximal/Distal Return Spring | 21 | 4

# Bearings

### 1. Place four bearings (30) in finger

proximal (3) and finger base (1) components

### 2. Secure using 2x10mm pins (32)

### 3. Repeat for all fingers

NOTE: Ensure all bearings spin, if not file/sand/deburr plastic

15

Step 1 and 2 | Step 1 and 2
Step 1 and 2
Step 1 and 2

# Finger Coupling Cable

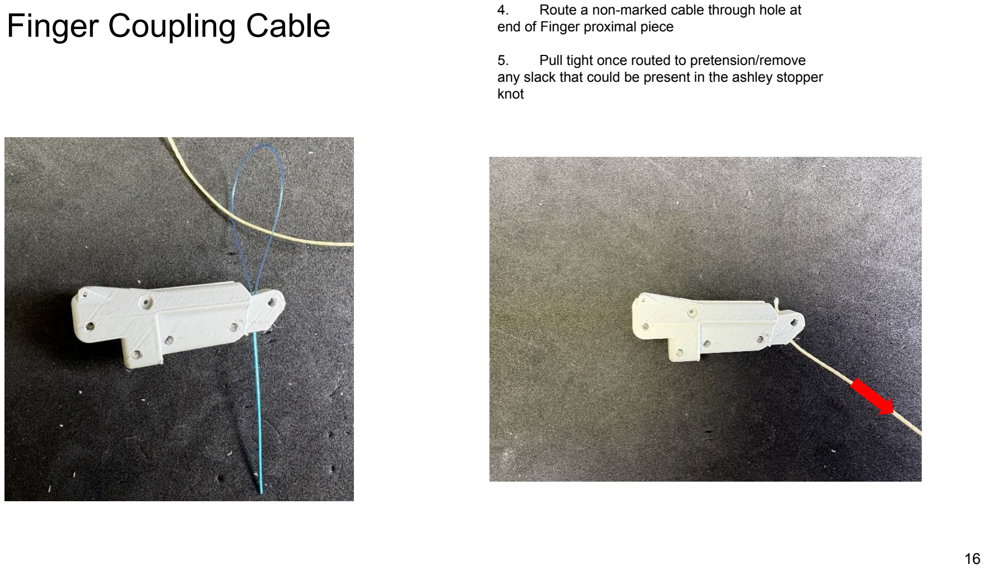
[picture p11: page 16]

16

### 4. Route a non-marked cable through hole at

end of Finger proximal piece

### 5. Pull tight once routed to pretension/remove

any slack that could be present in the ashley stopper knot

17

### 6. Install spring (21) connecting proximal (3)

and medial (4) components using two
1x10mm pins (31)

### 7. Install spring (22) on base of proximal using

one 1x10mm pin (31)

### 8. Connect proximal and medial sections

using one 2x14mm pin (34)

### 9. Thread coupling cable through bottom hole

on medial section | Step 6 and 7 | Step 8
Step 9 Step 9

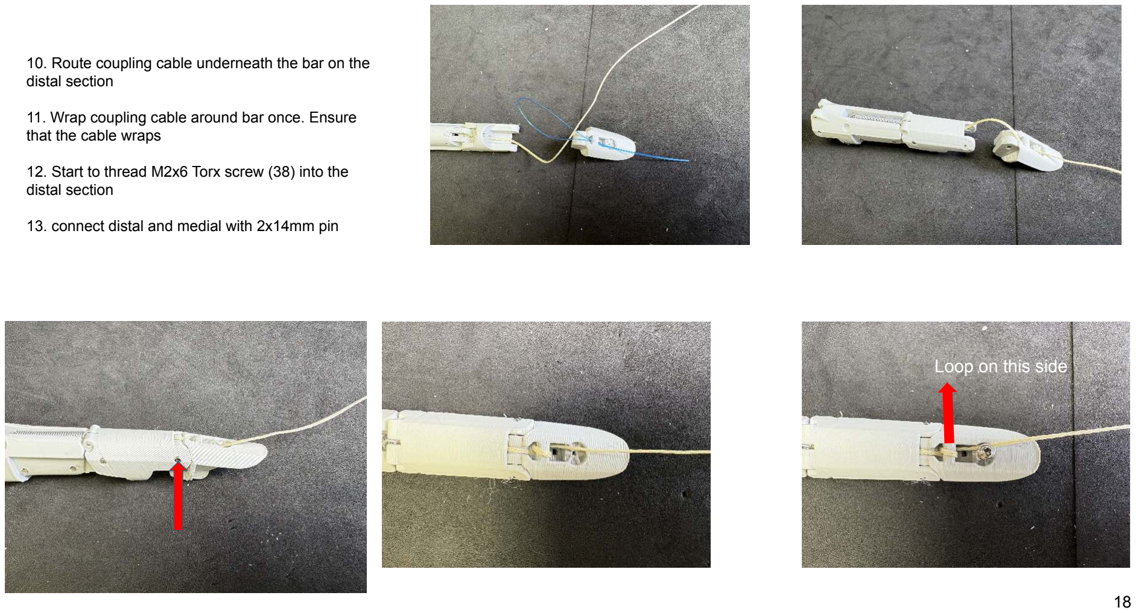
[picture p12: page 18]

18

### 10. Route coupling cable underneath the bar on the

distal section

### 11. Wrap coupling cable around bar once. Ensure

that the cable wraps

### 12. Start to thread M2x6 Torx screw (38) into the

distal section

### 13. connect distal and medial with 2x14mm pin

Loop on this side

19

### 13. Pull cable taut

### 14. Flex finger while maintaining

tension

### 15. Tighten screw until cable is

securely pinched

### 16. Distal/medial and

medial/proximal
angle should maintain the same angle when opening/closing the finger. See video

### 17. Repeat from step 1 for three

remaining fingers

# Thumb Assembly

20

Name | Part Number | QTY
Thumb Abduction Upper Servo Disk | 7 | 1
Thumb Abduction Lower Servo Disk | 8 | 1
Thumb Abduction Linkage Bar | 9 | 1
Thumb CMC Base | 10 | 1
Thumb MCP | 11 | 1
Thumb Proximal | 12 | 1
Thumb Distal | 13 | 1
Finger Coupling Cable | 26 | 1
UNDERSIZED 2x10 Pin | 32 | 5
2x5x2.5 bearing | 30 | 5
1x10 Pin | 31 | 2
M2x6 Flanged Torx Self Tapping Screw | 38 | 1
Finger Distal/Medial and Thumb Proximal/Distal Return Spring | 21 | 4
2x10 Pin | 33 | 1
Servo Motor Mount Plate | 43 | 1
Servo Motor Spline Screw M2.3x5 | 44 | 6
Servo Motor Plate Screw M2x4 | 45 | 1
Thumb CMC/MCP Return Spring | 23 | 1

### Tools:

Threading Tool
Pliers
Torx Driver
Loctite

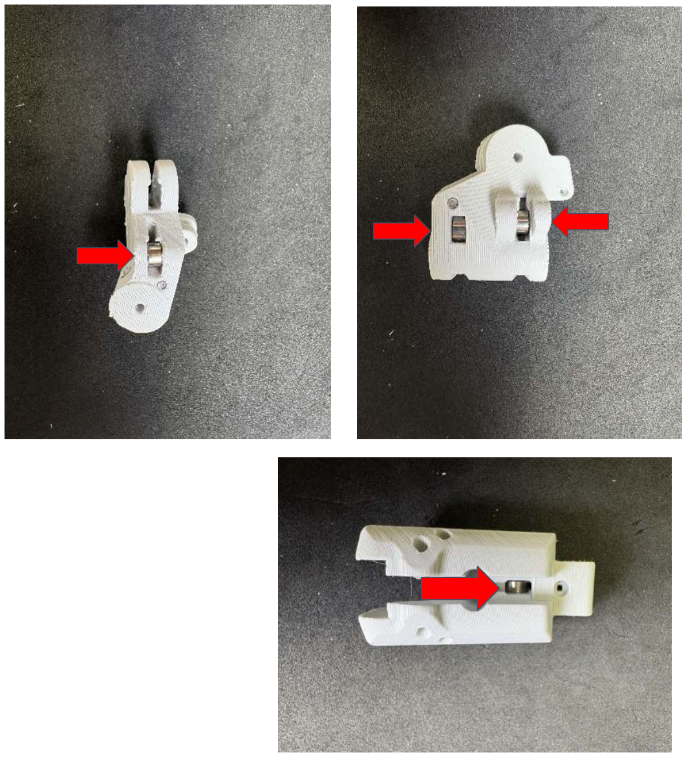
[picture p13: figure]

### 1. Insert bearings into thumb base (10)

and thumb MCP (11)

### 2. Secure using undersized 2x10mm pins

(32)

21

# Thumb Bearings

22

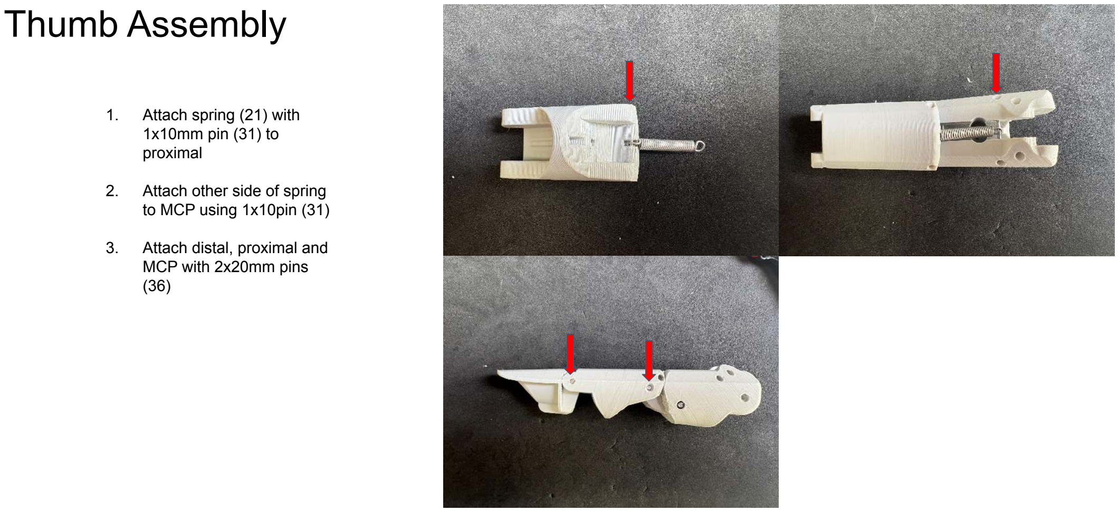
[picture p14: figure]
Thumb Assembly; 1. Attach spring (21) with 1x10mm pin (31) to proximal; 2. Attach other side of spring to MCP using 1x10pin (31); 3. Attach distal, proximal and MCP with 2x20mm pins (36)

23

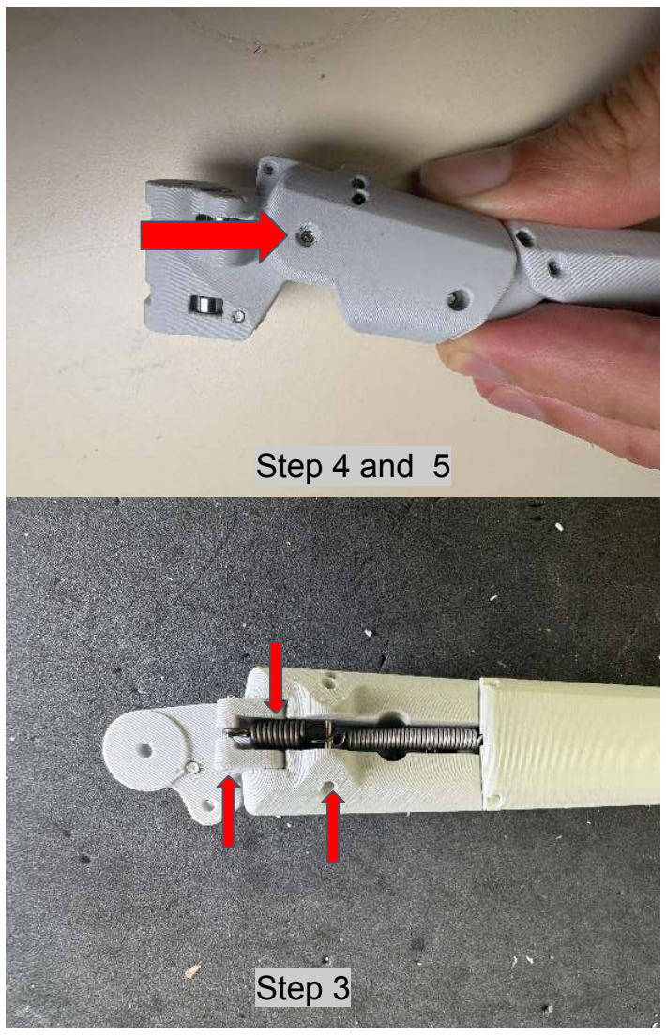
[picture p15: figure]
Step 4 and 5; Step 3

### 3. Connect thumb MCP to CMC using

thumb spring (25) and two 1x10mm pins

### 4. Insert CMC into MCP. Add bearing

between components

### 5. Secure using 2x20mm pin

# Thumb Coupling Cable

24

### 8. Thread a cable through in MCP

### 9. Pull taut

### 10. Thread through lower hole in

proximal and over distal

11. Add loop on crossmember. Note direction of loop

### 12. Tension and secure same as

fingers with 2x6mm torx screw (38)

Coupling Cable

# Servo ID and Assembly

25

### Tools:

Computer
Breadboard
Marker
Molex Connectors
Soldering Iron
Protoboard
Name | Part Number | QTY
Servo Motor | 42 | 7
Cable Spool | 6 | 6
Finger Pull Cable | 24 | 4
Pinky Pull Cable | 25 | 1
Thumb CMC Flex Cable | 27 | 1
Thumb Pull Cable | 28 | 1
Servo Motor Mount Plate | 43 | 6
Servo Motor Spline Screw M2.3x5 | 44 | 18
Servo Motor Plate Screw M2x4 | 45 | 6
Connection Cable | 47 | 1

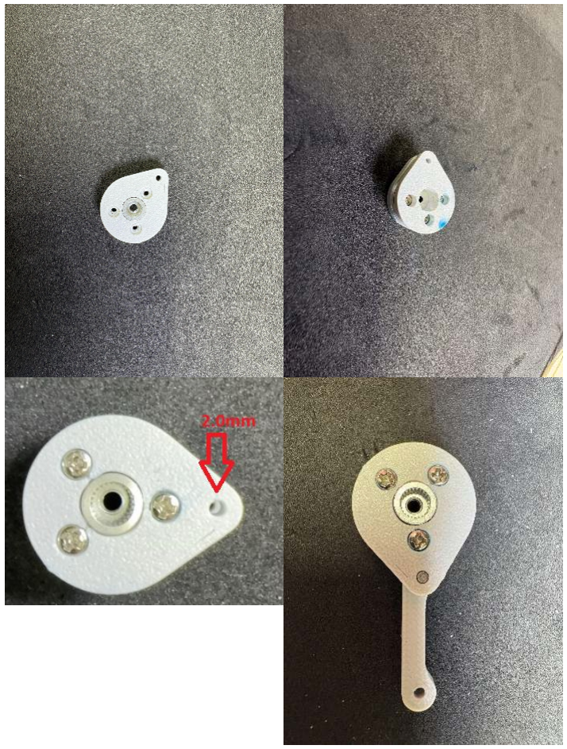
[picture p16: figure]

### 1. Place aluminum disk (43) into thumb servo lower disk (7). Secure using

M2x4 screws (45) with loctite

2. Add thumb servo upper disk (8) piece sandwiching the aluminum. Secure using M2x4 screws with loctite

### 3. Drill linkage holes in disks with 2mm drill (7 and 8)

### 4. Drill linkage hole in linkage bar with 2.1mm drill (9)

### 5. Place linkage bar between disks and secure using 2x10 pin (33). Note:

direction of linkage is important. Reference image

26

# Linkage Assembly

27

# Label Servos

### 1. Label all 7 servos with a sharpie or

paint marker with a unique number: 0, 1 ,2, 3 ,4, 5, 6

Reference image for location of number

28

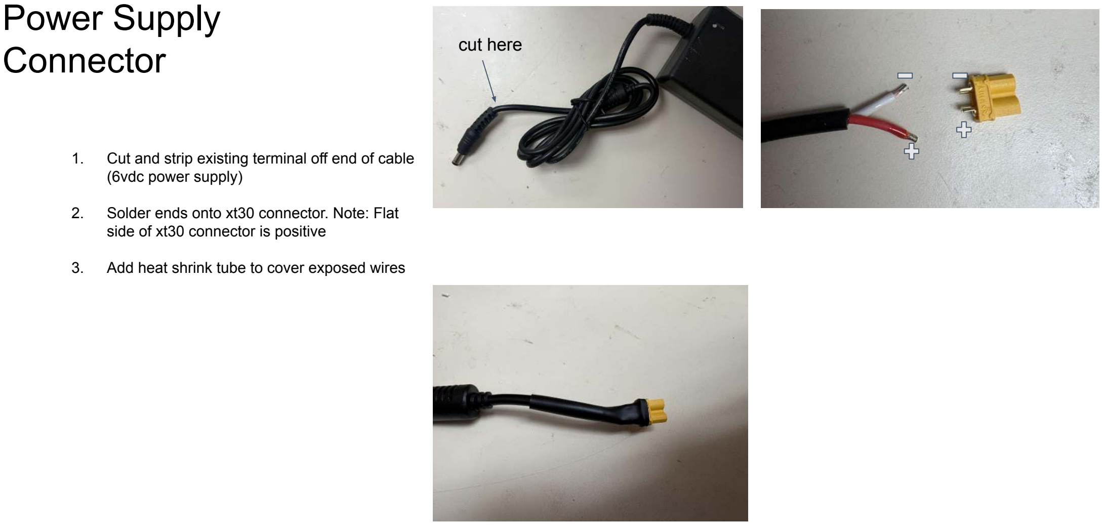
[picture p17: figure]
Power Supply Connector; (6vdc power supply); side of xt30 connector is positive; cut here

### 1. Cut and strip existing terminal off end of cable

### 2. Solder ends onto xt30 connector. Note: Flat

### 3. Add heat shrink tube to cover exposed wires

29

# Control Board

(not needed if PCB purchased)

Build a control board using the electrical schematic

Board can be built on a breadboard (no soldering required), custom PCB or protoboard

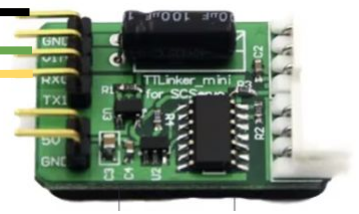
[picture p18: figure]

GREEN - RX
YELLOW - TX
BLACK - GROUND

Example protoboard

30

# Program Servos

### 3. Connect power (6vdc) to control board and esp32 to computer

### 4. https://docs.tetheria.ai/docs/GUI#setting-servo--ids

### 5. Follow steps to program and set ID for each servo

or

# Servo Spools

31

### 6. Screw cable spool (6)

into aluminum servo
mount (43) using three
screws (45). Apply loctite to threads before installing

### 7. Attach mount to servo

using large screw (44)
and loctite

### 8. Thread a cable into

servo

### 9. Mark length based on

servo number (example:
servo #1 = length 90mm)
10. Repeat for servos 1,
2, 3, 4, 5 and 6 | Length

# Thread finger servo cable

32

### 10. Install servo base and

MCP onto finger proximal
using 2x14mm pin

### 11. Thread the servo 6

cable through a finger base

### 12. Thread between

bearings on distal

### 13. Thread through top

medial hole and distal

### 14. Tie ashley stopper knot

at mark

15. Repeat for servos 3, 4,
and 5 | Pull Cable

Coupling Cable

33

# Servo Busbar

(not needed if PCB purchased)

### 16. Cut 7x8 protoboard

### 17. Place molex connectors as in

image. Note orientation.

### 18. Solder together using 22awg solid

wire as in image

### 19. Clean board to remove residual

flux

### 20. Cover wires in hot glue or liquid

electrical tape to protect against electrical shorting

NOTE: This step can be skipped by simply daisy chaining the servos together using the 3-way connects supplied with the servos

# Hand Base

34

### Tools:

Soldering Iron
Torx Driver
Philips Driver
Name | Part Number | QTY
Servo Frame | 14 | 1
Palm Front Frame | 15 | 1
Palm Rear Frame | 16 | 1
M3x6.4 Heat set insert | 41 | 4
M2x10 Countersunk Torx Self Tapping Screw | 39 | 12
M2x6 Flanged Torx Self Tapping Screw | 38 | 14
2x20 Pin | 36 | 1
UNDERSIZED 2x30 Pin | 37 | 1

35

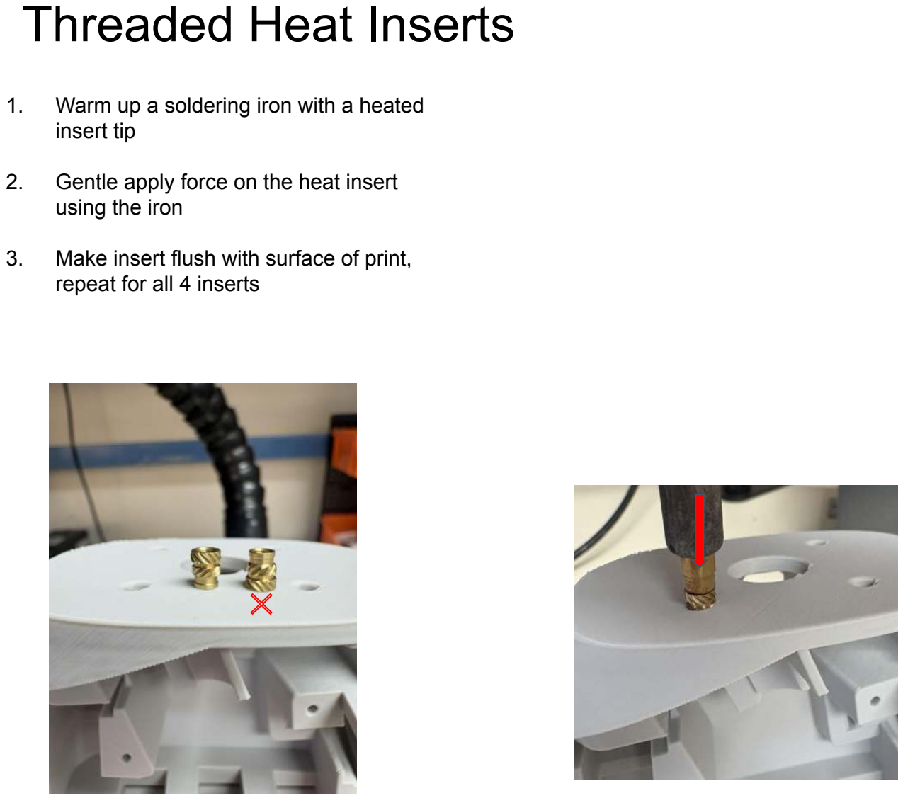
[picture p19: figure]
Threaded Heat Inserts; insert tip; using the iron; repeat for all 4 inserts

### 1. Warm up a soldering iron with a heated

### 2. Gentle apply force on the heat insert

3. Make insert flush with surface of print,

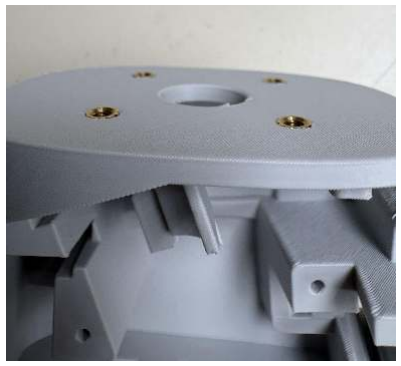
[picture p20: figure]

36

# Servo Frame

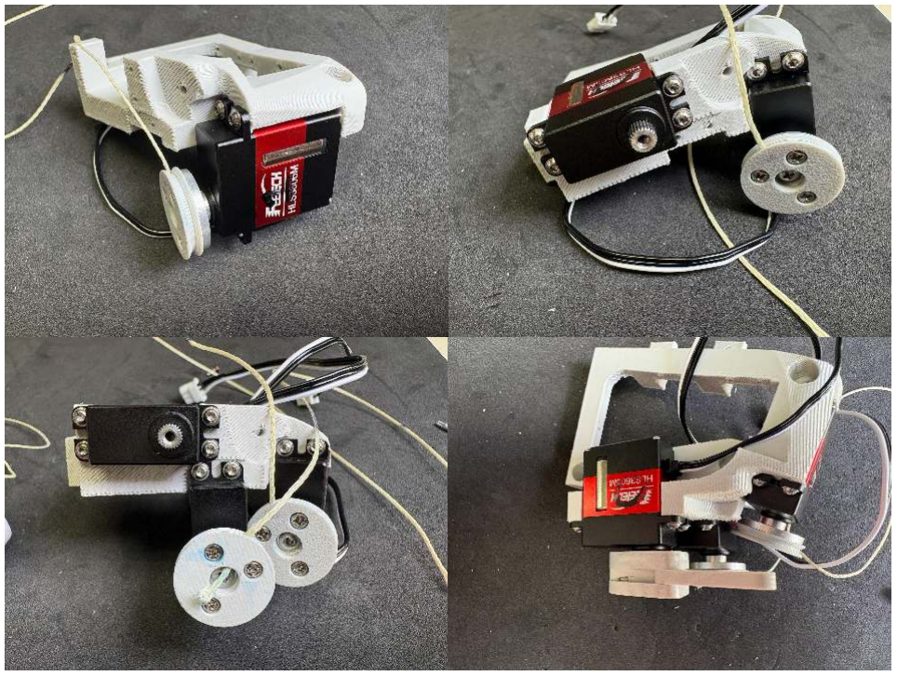
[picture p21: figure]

### 1. Place servo 1 onto servo frame (14) and secure with two

M2x6 self tapping screws (38)

### 2. Place servo 0 onto frame and secure with four M2x6 self

tapping screws

### 3. Place servo 2 onto frame and secure with two M2x6 self

tapping screws

### 4. Add linkage to servo 0 using screw (provided with servo)

with loctite

37

# Servo Frame Install

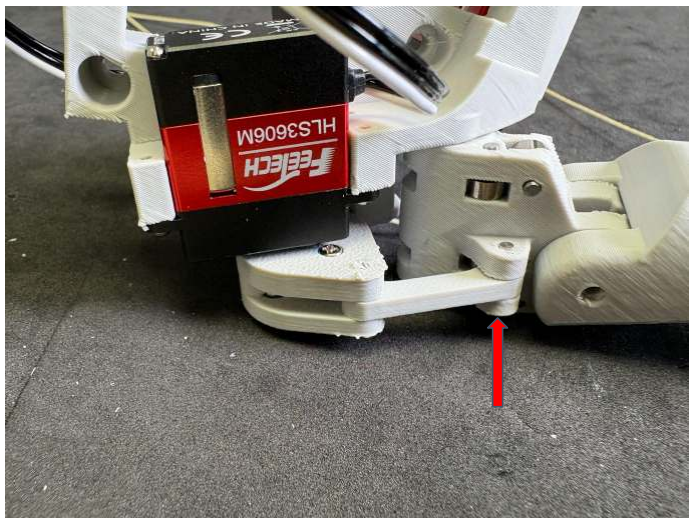
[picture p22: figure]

Insert 2x10 pin (34) between servo linkage and thumb CMC base (10)

# Install Finger Servos

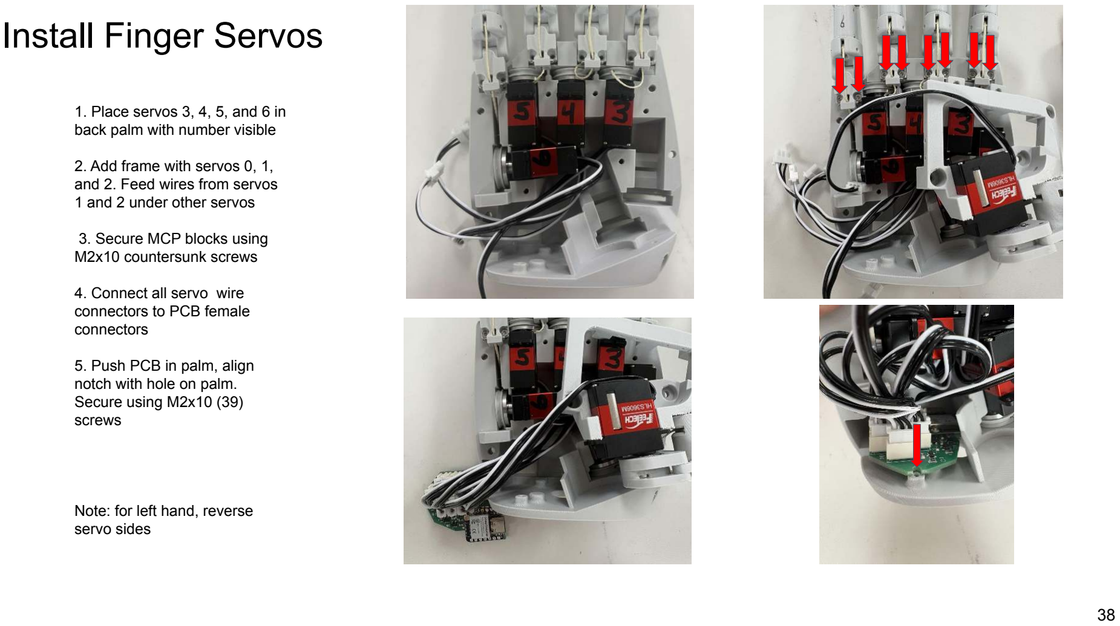
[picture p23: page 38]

38

### 1. Place servos 3, 4, 5, and 6 in

back palm with number visible

2. Add frame with servos 0, 1, and 2. Feed wires from servos

### 1 and 2 under other servos

### 3. Secure MCP blocks using

M2x10 countersunk screws

### 4. Connect all servo wire

connectors to PCB female
connectors

### 5. Push PCB in palm, align

notch with hole on palm.
Secure using M2x10 (39)
screws

Note: for left hand, reverse servo sides

39

# Install Finger Servos

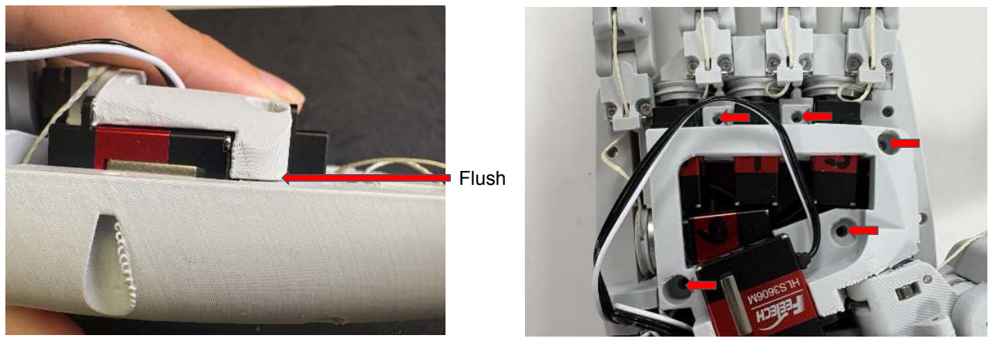
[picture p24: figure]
Flush

### 1. Push frame onto palm

### 2. Make sure frame contacts palm

without requiring excessive force. This step may take time to ensure no wires are crushed

### 4. Secure frame using M3x10

screws

40

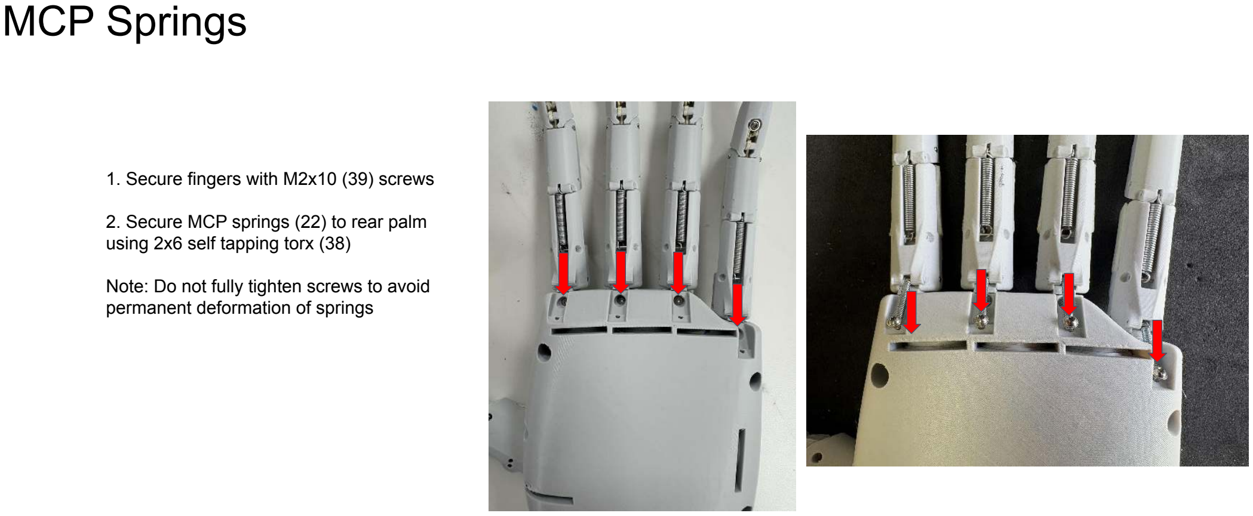
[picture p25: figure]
MCP Springs; 2. Secure MCP springs (22) to rear palm using 2x6 self tapping torx (38); permanent deformation of springs

### 1. Secure fingers with M2x10 (39) screws

Note: Do not fully tighten screws to avoid

# Thumb CMC Flex Cable

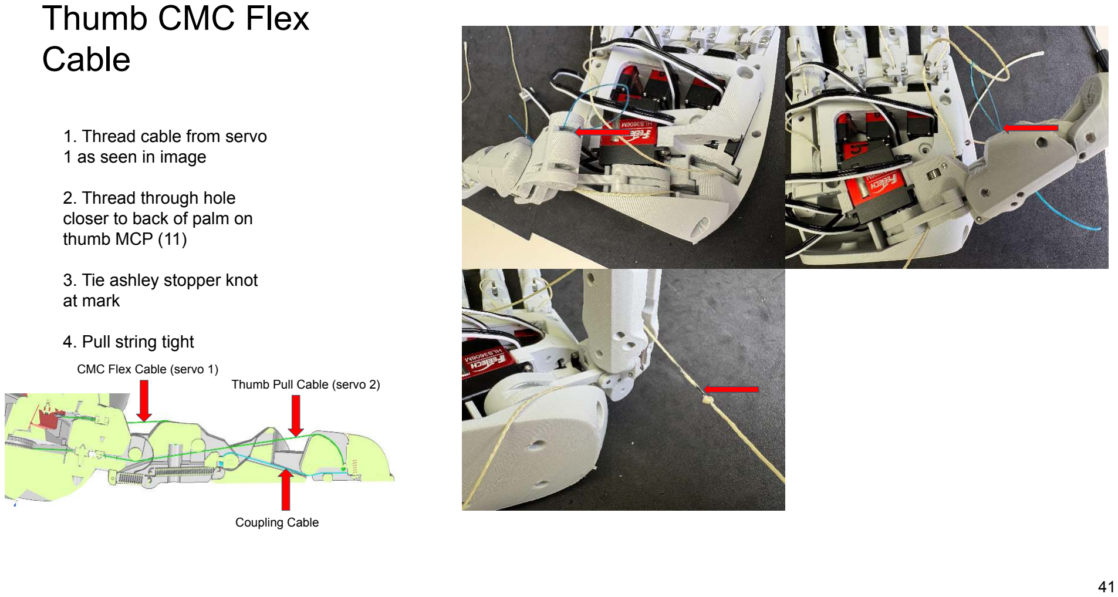
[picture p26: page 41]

41

### 1. Thread cable from servo 1 as seen in image

### 2. Thread through hole

closer to back of palm on
thumb MCP (11)

### 3. Tie ashley stopper knot

at mark

### 4. Pull string tight

Thumb Pull Cable (servo 2)

Coupling Cable

CMC Flex Cable (servo 1)

# Thumb Pull Cable

42

### 1. Thread cable from servo 2 as

seen in image

### 2. Thread through MCP (10)

around bearing

### 3. Thread through top hole in

thumb proximal (12)

### 4. Tie ashley stopper knot at

mark and pull tight

Thumb Pull Cable (servo 2)

Coupling Cable

CMC Flex Cable (servo 1)

43

# Thumb Bearings

### 25. Insert bearings (30) into

CMC base and push in as far in as possible

### 26. Insert 2x30mm pin (37) from

bottom until it is flush with the top surface

Note: applying pressure on bearings while installing pin will ensure they don’t fall out

44

# Front Palm

### 1. Secure servos 3,4,5, and 6 servos to frame using

2x6 self tapping torx screws (38)

### 2. Add front palm

### 3. Secure with four 3x10 self tapping screw on back of

hand

### 4. Trim all cables 5mm from knot

# Final Touches

45

### Tools:

Hot Glue
Super Glue
Name | Part Number | QTY
Palm Foam | 20 | 1
3x10 self tapping | 40 | 9
2x6 self tapping | 36 | 8
M2x10 Countersunk Torx Self Tapping Screw | 39 | 12
M2x6 Flanged Torx Self Tapping Screw | 38 | 14
UNDERSIZED 2x30 Pin | 37 | 1
Connection Cable | 47 | 1
TTLinker | 48 | 1

# Silicone Inserts Molds (optional)

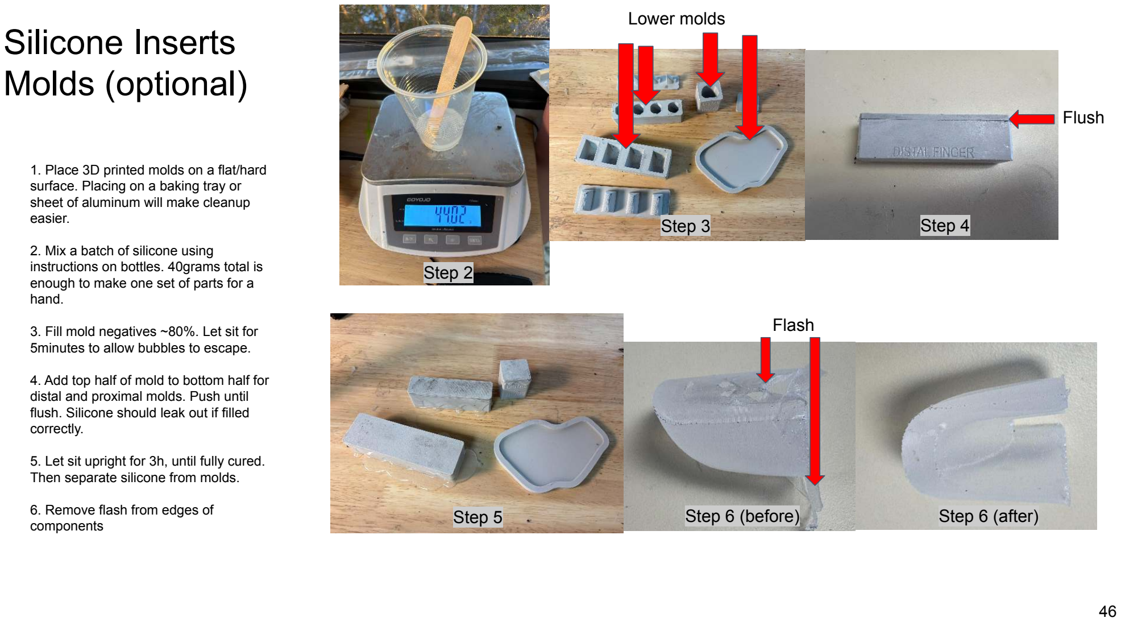
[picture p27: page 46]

46

### 1. Place 3D printed molds on a flat/hard

surface. Placing on a baking tray or sheet of aluminum will make cleanup easier.

### 2. Mix a batch of silicone using

instructions on bottles. 40grams total is enough to make one set of parts for a hand.

### 3. Fill mold negatives ~80%. Let sit for

5minutes to allow bubbles to escape.

### 4. Add top half of mold to bottom half for

distal and proximal molds. Push until flush. Silicone should leak out if filled correctly.

5. Let sit upright for 3h, until fully cured. Then separate silicone from molds.

### 6. Remove flash from edges of

components

Lower molds

Step 3
Step 2

Flush

Step 4

Flash

Step 5 | Step 6 (before) | Step 6 (after)

47

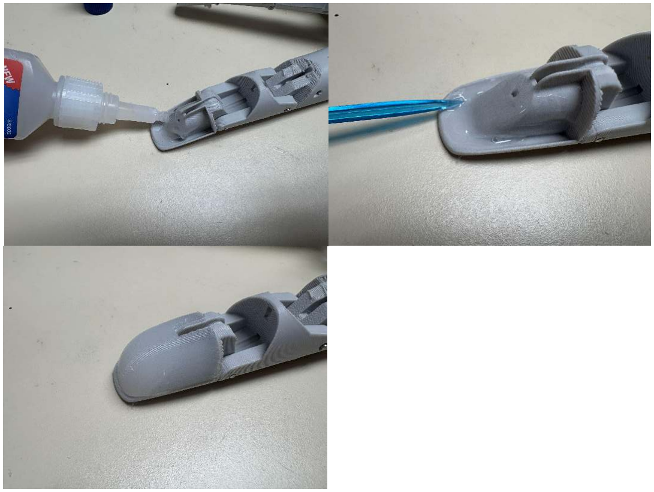
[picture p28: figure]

# Silicone Inserts (optional)

### 7. Apply silicone adhesive to internal side of

distal and proximal components

### 8. Spread around to create a uniform layer

on the plastic

### 9. Gently press on foam and hold for

30seconds, until glue solidifies

### 10. Repeat for all fingers and thumb

# Silicone Inserts (optional)

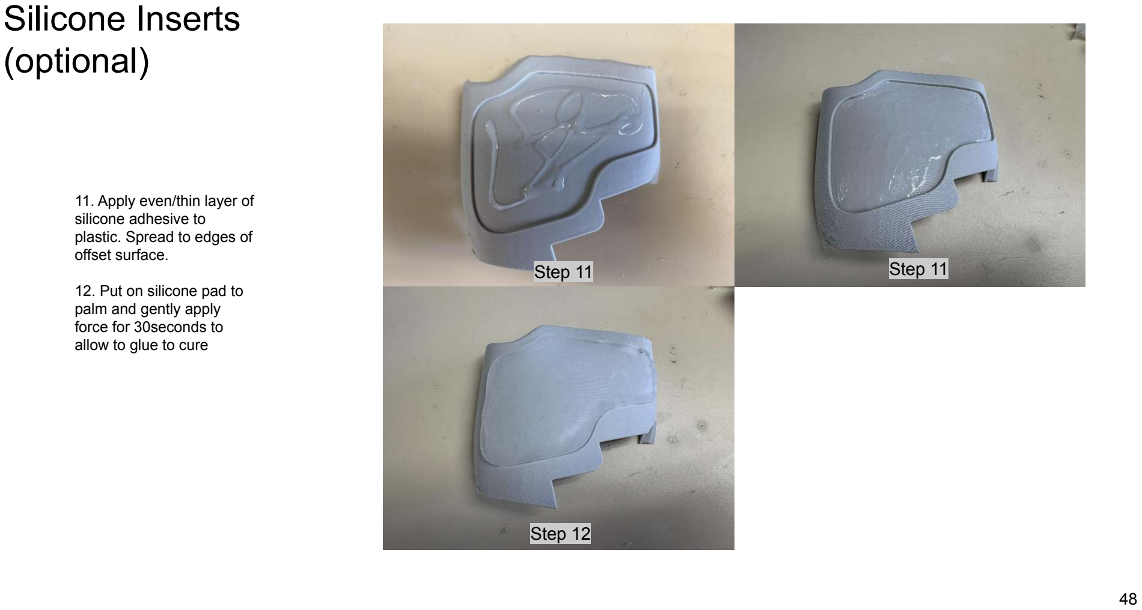
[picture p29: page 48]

48

### 11. Apply even/thin layer of

silicone adhesive to
plastic. Spread to edges of offset surface.

### 12. Put on silicone pad to

palm and gently apply
force for 30seconds to
allow to glue to cure
Step 11 Step 11
Step 12

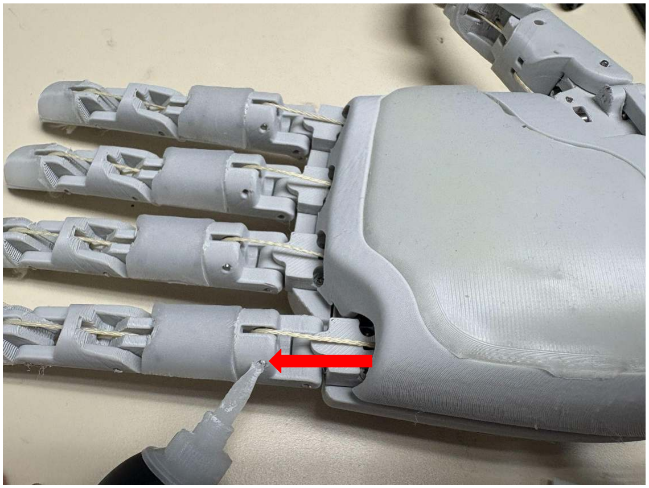
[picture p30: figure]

49

# High Cycling Protection (optional)

### 24. If using for high cycling >10,000

cycles per joint, apply superglue to every pin on both sides. This will secure them from sliding out.

50

Congratulations, you made it!

Your Aero hand is ready to meet the world. Let us know what you think of the hand.

https://tetheria.ai

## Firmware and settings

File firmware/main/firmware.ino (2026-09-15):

// Chestnut Robotics - Open Source Hand
// Aero Hand Firmware Source Code
#include <Arduino.h>
#include <Wire.h>
#include <HLSCL.h>
#include <Preferences.h>
#include "HandConfig.h"
#include "Homing.h"
#include "esp_system.h"

HLSCL hlscl;
Preferences prefs;

// ---- UART pins to the servo bus (ESP32-S3 XIAO: RX=2, TX=3) ----
#define SERIAL2_TX_PIN 3
#define SERIAL2_RX_PIN 2

// ---- Servo IDs (declare at top) ----
const uint8_t SERVO_IDS[7] = { 0, 1, 2, 3, 4, 5, 6 };

ServoData sd[7];

static inline void sendAckFrame(uint8_t header, const uint8_t* payload, size_t n);

// ---- Constants for Control Code byte ----
static const uint8_t HOMING        = 0x01;
static const uint8_t SET_ID         = 0x02;
static const uint8_t TRIM           = 0x03;
static const uint8_t CALIBRATE_MID  = 0x04;
static const uint8_t CTRL_POS       = 0x11;
static const uint8_t CTRL_TOR  = 0x12;
static const uint8_t GET_POS   = 0x22;
static const uint8_t GET_VEL   = 0x23;
static const uint8_t GET_CURR  = 0x24;
static const uint8_t GET_TEMP  = 0x25;
static const uint8_t SET_SPE   = 0x31;
static const uint8_t SET_TOR   = 0x32;

// ---- Defaults for SyncWritePosEx ----
static uint16_t g_speed[7]  = {32766,32766,32766,32766,32766,32766,32766};
static uint8_t  g_accel[7]  = {0,0,0,0,0,0,0};     // 0..255
static uint16_t g_torque[7] = {700,700,700,700,700,700,700}; // 0....1000
static const uint16_t HOLD_MAG = 5;       // the minimal torque actually commanded to the motors during the torque mode. Any torque below that will not be used.

// Last commanded torque per servo (signed)
static int16_t g_lastTorqueCmd[7] = {0};

// ---- Thermal torque limiting (GLOBAL PARAMETERS) ----
static uint8_t  TEMP_CUTOFF_C    = 70;    // °C cutoff
static uint16_t HOT_TORQUE_LIMIT = 500;   // clamp torque when motor exceeds TEMP_CUTOFF_C 

// ----- Registers / constants (Mapped as per Feetech Servo HLS3606M) -----
#define REG_ID                 0x05       // ID register
#define REG_CURRENT_LIMIT      28         // decimal address (word)
#define BROADCAST_ID           0xFE
#define SCAN_MIN               0
#define SCAN_MAX               253
#define REG_BLOCK_LEN          15
#define REG_BLOCK_START        56

// ----- Structure for the Metrics of Servo -------
struct ServoMetrics {
  uint16_t pos[7];
  uint16_t vel[7];
  uint16_t cur[7];
  uint16_t tmp[7];
};
static ServoMetrics gMetrics;

// -------- Global Control Mode State  ---------
enum ControlMode{
  MODE_POS=0,
  MODE_TORQUE=2
};
static ControlMode g_currentMode = MODE_POS;

// ----- Semaphores for Metrics and Bus for acquiring lock and release it -----
static SemaphoreHandle_t gMetricsMux;
SemaphoreHandle_t gBusMux = nullptr;

// ----- Homing module API Calls (provided below as .h/.cpp) --------
bool HOMING_isBusy();
void HOMING_start();

// ---- Helper function to read latest temp from servo
static inline uint8_t getTempC(uint8_t ch) {
  uint8_t t = 0;
  if (gMetricsMux) xSemaphoreTake(gMetricsMux, portMAX_DELAY);
  t = (uint8_t)gMetrics.tmp[ch];
  if (gMetricsMux) xSemaphoreGive(gMetricsMux);
  return t;
}

static inline bool isHot(uint8_t ch) {
  return getTempC(ch) >= TEMP_CUTOFF_C;
}

static inline uint16_t u16_min(uint16_t a, uint16_t b) { return (a < b) ? a : b; }

// ---- Set-ID helpers for setting ID ---
extern void runReIdScanAndSet(uint8_t Id, uint16_t currentLimit);
static volatile int g_lastFoundId; 

// ----- Helper Functions for Set-ID Mode -----
static bool scanRequireSingleServo(uint8_t* outId, uint8_t requestedNewId) {
  uint8_t first = 0xFF;
  int count = 0;
  if (gBusMux) xSemaphoreTake(gBusMux, portMAX_DELAY);
  for (int id = SCAN_MIN; id <= SCAN_MAX; ++id) {
    if (id == BROADCAST_ID) continue;        
    (void)hlscl.Ping((uint8_t)id);
    if (!hlscl.getLastError()) {
      if (count == 0) first = (uint8_t)id;
      ++count;
      if (count > 1) break;                    
    }
  }
  if (gBusMux) xSemaphoreGive(gBusMux);
  if (count == 1) {
    if (outId) *outId = first;
    return true;
  }
  if (count == 0) {
    uint8_t ack6[6] = { 0xFF, 0x00, requestedNewId, 0x00, 0x00, 0x00 };
    sendAckFrame(SET_ID, ack6, sizeof(ack6));
    return false;
  }
  uint8_t ack14[14] = {0xFF, 0xFF, 0xFF, 0xFF, 0xFF, 0xFF, 0xFF, 0xFF, 0x00, 0x00, 0x00, 0x00, 0x00, 0x00};
  sendAckFrame(SET_ID, ack14, sizeof(ack14));
  return false;
}
static void sendSetIdAck(uint8_t oldId, uint8_t newId, uint16_t curLimitWord) {
  uint16_t vals[7] = {0};
  vals[0] = oldId;
  vals[1] = newId;
  vals[2] = curLimitWord;
  uint8_t out[2 + 7*2];
  out[0] = SET_ID;  // 0x03
  out[1] = 0x00;    // filler
  for (int i = 0; i < 7; ++i) {
    out[2 + 2*i + 0] = (uint8_t)(vals[i] & 0xFF);
    out[2 + 2*i + 1] = (uint8_t)((vals[i] >> 8) & 0xFF);
  }
  Serial.write(out, sizeof(out));
}
// ---- Helper function to save and loadManual extends from NVS ------
static void loadManualExtendsFromNVS() {
  prefs.begin("hand", true);  // read-only
  for (uint8_t i = 0; i < 7; ++i) {
    // Store extends per logical channel index, not servo bus ID.
    String key = "ext" + String(i);
    int v = prefs.getInt(key.c_str(), -1);
    if (v >= 0 && v <= 4095) {
      sd[i].extend_count = v;
    }
  }
}

static void saveExtendsToNVS() {
  prefs.begin("hand", false);  // RW
  for (uint8_t i = 0; i < 7; ++i) {
    // Store extends per logical channel index, not servo bus ID.
    String kext = "ext" + String(i);
    prefs.putInt(kext.c_str(), (int)sd[i].extend_count);
  }
  prefs.end();
}

// -------- Soft-Limit Safety for Servo motors
static void checkAndEnforceSoftLimits()
{
  static bool torqueLimited[7] = {false};
  static uint32_t lastCheckMs = 0;
  uint32_t now = millis();
  if (now - lastCheckMs < 20) return;
  lastCheckMs = now;

  if (g_currentMode != MODE_TORQUE) {
    // Only apply soft limits during torque control.
    for (int i = 0; i < 7; ++i) torqueLimited[i] = false;
    return;
  }

  if (gBusMux) xSemaphoreTake(gBusMux, portMAX_DELAY);
  for (uint8_t i = 0; i < 7; ++i) {
    uint8_t id = SERVO_IDS[i];
    int pos = hlscl.ReadPos(id);
    if (pos < 0) pos += 32768;
    uint16_t raw = pos % 4096;
    uint16_t ext = sd[i].extend_count;
    uint16_t gra = sd[i].grasp_count;
    uint16_t rawMin = min(ext, gra);
    uint16_t rawMax = max(ext, gra);
    bool inRange = (raw >= rawMin && raw <= rawMax);
    if (!inRange && !torqueLimited[i]) {
      int16_t limitedTorque = (g_lastTorqueCmd[i] >= 0) ? 200 : -200;
      hlscl.WriteEle(id, limitedTorque);
      torqueLimited[i] = true;
    } else if (inRange && torqueLimited[i]) {
      hlscl.WriteEle(id, g_lastTorqueCmd[i]);
      torqueLimited[i] = false;
    }
  }
  if (gBusMux) xSemaphoreGive(gBusMux);
}


// ---- Helper function  for raw to U16 and U16 to raw ----
static inline uint16_t mapRawToU16(uint8_t ch, uint16_t raw) {
  int32_t ext  = sd[ch].extend_count;
  int32_t gra  = sd[ch].grasp_count;
  int32_t span = gra - ext;
  if (span == 0) return 0;  // avoid divide-by-zero
  int32_t val = ((int32_t)(raw - ext) * 65535L) / span;
  //Clamp
  if (val < 0) val = 0;
  if (val > 65535) val = 65535;
  return (uint16_t)val;
}
static inline uint16_t mapU16ToRaw(uint8_t ch, uint16_t u16) {
  int32_t ext = sd[ch].extend_count;
  int32_t gra = sd[ch].grasp_count;
  int32_t raw32;
  if (ext == 0 && gra == 0) {
    raw32 = ((uint64_t)u16 * 4095u) / 65535u;
  } else {
    raw32 = ext + ((int64_t)u16 * (gra - ext)) / 65535LL;
  }
  // clamp
  if (raw32 < 0)    raw32 = 0;
  if (raw32 > 4095) raw32 = 4095;
  return (uint16_t)raw32;
}

// ---- Helper Functions for u16, Decode to sign and copy values in u16 format----
static inline uint16_t leu_u16(const uint8_t *p) {
  return (uint16_t)p[0] | ((uint16_t)p[1] << 8);
}
static inline int16_t decode_signmag15(uint8_t lo, uint8_t hi) {
  uint16_t mag = ((uint16_t)(hi & 0x7F) << 8) | lo;  // 15-bit magnitude
  return (hi & 0x80) ? -(int16_t)mag : (int16_t)mag;
}
static inline void copy7_u16(uint16_t dst[7], const uint16_t src[7]) {
  for (int i = 0; i < 7; ++i) dst[i] = src[i];
}

// ----- Helper function to send u16 frame for POS,SPD,VEL,CURR and sendACK Packet ----
static inline void sendU16Frame(uint8_t header, const uint16_t data[7]) {
  uint8_t out[2 + 7*2];
  out[0] = header;
  out[1] = 0x00; // filler
  for (int i = 0; i < 7; ++i) {
    out[2 + 2*i + 0] = (uint8_t)(data[i] & 0xFF);
    out[2 + 2*i + 1] = (uint8_t)((data[i] >> 8) & 0xFF);
  }
  Serial.write(out, sizeof(out)); 
}
static inline void sendAckFrame(uint8_t header, const uint8_t* payload, size_t n) {
  uint8_t out[16];
  out[0] = header;
  out[1] = 0x00; // filler
  memset(out + 2, 0, 14);
  if (payload && n) {
    if (n > 14) n = 14;
    memcpy(out + 2, payload, n);
  }
  Serial.write(out, sizeof(out));
}

// ----- Functions to Send POS, VEL, CURR, TEMP -----
void sendPositions() {
  uint16_t buf[7];
  xSemaphoreTake(gMetricsMux, portMAX_DELAY);
  copy7_u16(buf, gMetrics.pos);
  xSemaphoreGive(gMetricsMux);
  sendU16Frame(GET_POS, buf);
}
void sendVelocities() {
  uint16_t buf[7];
  xSemaphoreTake(gMetricsMux, portMAX_DELAY);
  copy7_u16(buf, gMetrics.vel);
  xSemaphoreGive(gMetricsMux);
  sendU16Frame(GET_VEL, buf);
}
void sendCurrents() {
  uint16_t buf[7];
  xSemaphoreTake(gMetricsMux, portMAX_DELAY);
  copy7_u16(buf, gMetrics.cur);
  xSemaphoreGive(gMetricsMux);
  sendU16Frame(GET_CURR, buf);
}
void sendTemps() {
  uint16_t buf[7];
  xSemaphoreTake(gMetricsMux, portMAX_DELAY);
  copy7_u16(buf, gMetrics.tmp);
  xSemaphoreGive(gMetricsMux);
  sendU16Frame(GET_TEMP, buf);
}

// ----- Task - Sync Read running always on Core 1 ----- 
static void TaskSyncRead_Core1(void *arg) {
  uint8_t  rx[REG_BLOCK_LEN];          // 15 bytes
  uint16_t pos[7], vel[7], cur[7], tmp[7];
  const TickType_t period = pdMS_TO_TICKS(10);   // Change Frequency of Running here, 5 -200 Hz, 10-100 Hz, 20 -50 Hz
  TickType_t nextWake = xTaskGetTickCount();
  for (;;) {
    // try-lock: if control is using the bus, skip this cycle
    if (gBusMux && xSemaphoreTake(gBusMux, 0) != pdTRUE) {
      vTaskDelayUntil(&nextWake, period);
      continue;
    }
    bool ok = true;
    // one TX for the whole group (15-byte slice)
    hlscl.syncReadPacketTx((uint8_t*)SERVO_IDS, 7, REG_BLOCK_START, REG_BLOCK_LEN);
    for (uint8_t i = 0; i < 7; ++i) {
      if (!hlscl.syncReadPacketRx(SERVO_IDS[i], rx)) { ok = false; break; }
      uint16_t raw = leu_u16(&rx[0]);
      pos[i] = mapRawToU16(i,raw);                     // Position (unsigned)
      vel[i] = decode_signmag15(rx[2], rx[3]);                  // velocity (signed)
      tmp[i] = rx[7];                                           // temperature (unsigned, 1 byte)
      cur[i] = decode_signmag15(rx[13], rx[14]);                // current (signed)
      //vTaskDelay(1);
    }
    if (gBusMux) xSemaphoreGive(gBusMux);
    if (ok) {
      xSemaphoreTake(gMetricsMux, portMAX_DELAY);
      for (int i = 0; i < 7; ++i) {
        gMetrics.pos[i] = pos[i];
        gMetrics.vel[i] = vel[i];
        gMetrics.tmp[i] = tmp[i];
        gMetrics.cur[i] = cur[i];
      }
      xSemaphoreGive(gMetricsMux);
    } 
    vTaskDelayUntil(&nextWake, period);
  }
}
//Set-ID and Trim Servo functions
static bool handleSetIdCmd(const uint8_t* payload) {
  // Parse request: two u16 words, little-endian
  uint16_t w0 = (uint16_t)payload[0] | ((uint16_t)payload[1] << 8); // newId in low byte
  uint16_t w1 = (uint16_t)payload[2] | ((uint16_t)payload[3] << 8); // requested current limit
  uint8_t  newId    = (uint8_t)(w0 & 0xFF);
  uint16_t reqLimit = (w1 > 1023) ? 1023 : w1;
  // Invalid newId → ACK with oldId=0xFF, newId, cur=0
  if (newId > 253 || newId ==BROADCAST_ID) {
    uint8_t ack[6] = { 0xFF, 0x00, newId, 0x00, 0x00, 0x00 };
    sendAckFrame(SET_ID, ack, sizeof(ack));
    return true;
  }
  // Find any servo present
  uint8_t oldId = 0xFF;
  if (!scanRequireSingleServo(&oldId, newId)) return true; 
  
  if (newId != oldId) {
  if (gBusMux) xSemaphoreTake(gBusMux, portMAX_DELAY);
  (void)hlscl.Ping(newId);
  bool taken = !hlscl.getLastError();
  if (gBusMux) xSemaphoreGive(gBusMux);
  if (taken) {
    uint8_t ack14[14] = { oldId, 0x00, newId, 0x00, 0x00, 0x00, 0x00, 0x00, 0x00, 0x00, 0x00, 0x00, 0x00, 0x00};
    sendAckFrame(SET_ID, ack14, sizeof(ack14));
    return true;
  }
  }
  if (gBusMux) xSemaphoreTake(gBusMux, portMAX_DELAY);
  (void)hlscl.unLockEprom(oldId);
  (void)hlscl.writeWord(oldId, REG_CURRENT_LIMIT, reqLimit);
  uint8_t targetId = oldId;
  if (newId != oldId) {
    (void)hlscl.writeByte(oldId, REG_ID, newId);   // REG_ID = 0x05
    targetId = newId;
  }
  (void)hlscl.LockEprom(targetId);
  
  // Read back limit for ACK
  uint16_t curLimitRead = 0;
  int rd = hlscl.readWord(targetId, REG_CURRENT_LIMIT);
  if (rd >= 0) curLimitRead = (uint16_t)rd;
  if (gBusMux) xSemaphoreGive(gBusMux);
  // Build 6-byte payload: oldId(LE16), newId(LE16), curLimit(LE16) and send
  uint8_t ack[6];
  ack[0] = oldId;                      // oldId lo
  ack[1] = 0x00;                       // oldId hi
  ack[2] = targetId;                   // newId lo
  ack[3] = 0x00;                       // newId hi
  ack[4] = (uint8_t)(curLimitRead & 0xFF);
  ack[5] = (uint8_t)((curLimitRead >> 8) & 0xFF);
  sendAckFrame(SET_ID, ack, sizeof(ack));
  return true;
}
static bool handleTrimCmd(const uint8_t* payload) {
  // Parse little-endian fields
  uint16_t rawCh  = (uint16_t)payload[0] | ((uint16_t)payload[1] << 8);
  uint16_t rawDeg = (uint16_t)payload[2] | ((uint16_t)payload[3] << 8);
  int      ch      = (int)rawCh;         // 0..6
  int16_t  degrees = (int16_t)rawDeg;    // signed degrees
  // Validate channel (0..6)
  if (ch < 0 || ch >= 7) {
    // Optionally send a NACK or silent-accept to preserve framing
    return true;
  }
  // Degrees -> counts (≈11.375 counts/deg), clamp to 0..4095
  int delta_counts = (int)((float)degrees * 11.375f);
  int new_ext = (int)sd[ch].extend_count + delta_counts;
  if (new_ext < 0)    new_ext = 0;
  if (new_ext > 4095) new_ext = 4095;
  sd[ch].extend_count = (uint16_t)new_ext;
  // Persist to NVS
  prefs.begin("hand", false);
  prefs.putInt(String("ext" + String(ch)).c_str(), sd[ch].extend_count);
  prefs.end();
  int present = -1;
  if (gBusMux) xSemaphoreTake(gBusMux, portMAX_DELAY);
  present = hlscl.ReadPos(SERVO_IDS[ch]);
  if (gBusMux) xSemaphoreGive(gBusMux);

  uint16_t present_raw = present < 0 ? 0xFFFF : (uint16_t)(((present % 4096) + 4096) % 4096);
  uint16_t ack_values[7] = {
      (uint16_t)ch, sd[ch].extend_count, present_raw, 0, 1, 0, 0};
  sendU16Frame(TRIM, ack_values);
  return true;
}

static bool handleCalibrateMidCmd(const uint8_t* payload) {
  uint16_t rawCh = leu_u16(payload);
  uint16_t present_raw = 0xFFFF;
  uint16_t present_u16 = 0;
  uint16_t status = 1;

  if (rawCh < 7 && g_currentMode == MODE_POS) {
    uint8_t ch = (uint8_t)rawCh;
    uint8_t servoID = SERVO_IDS[ch];
    int present = -1;

    if (gBusMux) xSemaphoreTake(gBusMux, portMAX_DELAY);
    bool calibrated = hlscl.CalibrationOfs(servoID) != 0;
    delay(30);
    if (calibrated) present = hlscl.ReadPos(servoID);
    bool mode_set = hlscl.ServoMode(servoID) != 0;
    bool locked = hlscl.LockEprom(servoID) != 0;
    bool position_set = false;
    if (present >= 0 && mode_set && locked) {
      position_set = hlscl.WritePosEx(
          servoID, present, g_speed[ch], g_accel[ch], g_torque[ch]) != 0;
    }
    bool torque_enabled = hlscl.EnableTorque(servoID, 1) != 0;
    if (gBusMux) xSemaphoreGive(gBusMux);

    if (calibrated && present >= 0 && mode_set && locked && position_set && torque_enabled) {
      present_raw = (uint16_t)(((present % 4096) + 4096) % 4096);
      present_u16 = mapRawToU16(ch, present_raw);
      if (present_raw >= 2000 && present_raw <= 2096) status = 0;
    }
  }

  uint16_t ack_values[7] = {rawCh, present_raw, present_u16, status, 1, 0, 0};
  sendU16Frame(CALIBRATE_MID, ack_values);
  return true;
}

static bool handleSetSpeedCmd(const uint8_t* payload)
{
  uint16_t rawId = (uint16_t)payload[0] | ((uint16_t)payload[1] << 8);
  uint16_t rawSpd = (uint16_t)payload[2] | ((uint16_t)payload[3] << 8);
  if (rawId >= 7) {
    //invalid index of servo actuator - So give error code (0–6 valid)
    uint8_t ack[4] = {0xFF, 0xFF, 0x00, 0x00};
    sendAckFrame(SET_SPE, ack, sizeof(ack));
    return true;
  }
  if (rawSpd > 32766) rawSpd = 32766;  // clamp
  g_speed[rawId] = rawSpd;
  // ACK back: servo id and speed
  uint8_t ack[4];
  ack[0] = (uint8_t)(rawId & 0xFF);
  ack[1] = (uint8_t)((rawId >> 8) & 0xFF);
  ack[2] = (uint8_t)(rawSpd & 0xFF);
  ack[3] = (uint8_t)((rawSpd >> 8) & 0xFF);
  sendAckFrame(SET_SPE, ack, sizeof(ack));
  return true;
}
static bool handleSetTorCmd(const uint8_t* payload)
{
  uint16_t rawId = (uint16_t)payload[0] | ((uint16_t)payload[1] << 8);
  uint16_t rawTor = (uint16_t)payload[2] | ((uint16_t)payload[3] << 8);
  // Validate ID range (0..6)
  if (rawId >= 7) {
    uint8_t ack[4] = {0xFF, 0xFF, 0x00, 0x00};  // invalid ID ack
    sendAckFrame(SET_TOR, ack, sizeof(ack));
    return true;
  }
  if (rawTor > 1023) rawTor = 1023;
  // Update the per-servo torque value
  g_torque[rawId] = rawTor;
  uint8_t ack[4];
  ack[0] = (uint8_t)(rawId & 0xFF);
  ack[1] = (uint8_t)((rawId >> 8) & 0xFF);
  ack[2] = (uint8_t)(rawTor & 0xFF);
  ack[3] = (uint8_t)((rawTor >> 8) & 0xFF);
  sendAckFrame(SET_TOR, ack, sizeof(ack));
  return true;
}

// ----- Returns true if a valid 16-byte frame was consumed and handled -----
static bool handleHostFrame(uint8_t op) {
  // Wait until full frame is buffered: filler + 14 payload
  while (Serial.available() < 15) { /* wait */ }
  uint8_t buf[15];
  for (int i = 0; i < 15; ++i) {
    int ch = Serial.read(); if (ch < 0) return false;
    buf[i] = (uint8_t)ch;
  }
  const uint8_t* payload = &buf[1]; // buf[0] = filler 0x00 (ignored)

  switch (op) {
    case CTRL_POS: {
      int16_t pos[7];
      for (int i = 0; i < 7; ++i) {
        uint16_t u16 = (uint16_t)payload[2*i] | ((uint16_t)payload[2*i+1] << 8);
        uint8_t  ch  = i;
        pos[i] = mapU16ToRaw(ch, u16);
      }

      // Torque Servo limit - If motor crosses the TEMP_CUTOFF_C, then keep HOT_TORQUE_LIMIT as the torque
      uint16_t torque_eff[7];
      for (int i = 0; i < 7; ++i) {
        uint16_t base = g_torque[i]; // 0..1023
        if (isHot((uint8_t)i)) {
          base = u16_min(base, HOT_TORQUE_LIMIT);
        }
        torque_eff[i] = base;
      }

      if (gBusMux) xSemaphoreTake(gBusMux, portMAX_DELAY);
      if (g_currentMode != MODE_POS) {
        for (int i = 0; i < 7; ++i) {
          uint8_t id = SERVO_IDS[i];
          hlscl.ServoMode(id);
        }
        g_currentMode = MODE_POS;
      }
      hlscl.SyncWritePosEx((uint8_t*)SERVO_IDS, 7, pos, g_speed, g_accel, torque_eff);
      if (gBusMux) xSemaphoreGive(gBusMux);
      return true;
    }

    case CTRL_TOR: 
    {   
      int16_t torque_cmd[7]; 
      for (int i = 0; i < 7; ++i) 
      {
        uint16_t mag = (uint16_t)payload[2*i] | ((uint16_t)payload[2*i + 1] << 8); 
        if (mag > 1000) mag = 1000; 
        if (mag < HOLD_MAG) mag = HOLD_MAG;
        if (isHot((uint8_t)i)) {
          mag = u16_min(mag, HOT_TORQUE_LIMIT);
        }
        int grasp_sign = (sd[i].extend_count > sd[i].grasp_count) ? +1 : -1;
        torque_cmd[i] = (int16_t)(grasp_sign * (int)mag);
      } 
      for (int i = 0; i < 7; ++i) {
        g_lastTorqueCmd[i] = torque_cmd[i];
      }

      if (gBusMux) xSemaphoreTake(gBusMux, portMAX_DELAY);

      if (g_currentMode != MODE_TORQUE) 
      { 
        for (int i = 0; i < 7; ++i) 
        { 
          uint8_t id = SERVO_IDS[i]; 
          hlscl.EleMode(id); 
        } 
        g_currentMode = MODE_TORQUE;
      } 
      for (int i = 0; i < 7; ++i) 
      { 
        uint8_t id = SERVO_IDS[i]; 
        hlscl.WriteEle(id, torque_cmd[i]); 
      } 
      if (gBusMux) xSemaphoreGive(gBusMux); 
      return true; 
    }

    case SET_TOR: {
      return handleSetTorCmd(payload);
    }

    case SET_SPE: {
      return handleSetSpeedCmd(payload);
    }

    case HOMING: {
      HOMING_start();   // blocks
      saveExtendsToNVS();
      sendAckFrame(HOMING, nullptr, 0);
      return true;
    }

    case SET_ID: {
      return handleSetIdCmd(payload);
    }

    case TRIM: {
      return handleTrimCmd(payload);
    }

    case CALIBRATE_MID: {
      return handleCalibrateMidCmd(payload);
    }

    case GET_POS: {
      sendPositions();
      return true;
    }

    case GET_VEL: {
      sendVelocities();
      return true;
    }

    case GET_TEMP: {
      sendTemps();
      return true;
    }

    case GET_CURR: {
      sendCurrents();
      return true;
    }

    default:
      //Unknown Control Code — consume frame to preserve alignment
      return true;
  }
}
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
void loop() {
  static uint32_t last_cmd_ms = 0; 

  // Gate all host input during homing
  if (HOMING_isBusy()) {
    while (Serial.available()) { Serial.read(); }
    vTaskDelay(pdMS_TO_TICKS(5));
    return;
  }

  // ------ Soft Limit Check -------
  checkAndEnforceSoftLimits();

  // Process exactly one complete 16-byte frame when available
  if (Serial.available() >= 16) {
    int op = Serial.read();
    if (op >= 0) {
      if (handleHostFrame((uint8_t)op)) {
        last_cmd_ms = millis();
        return;
      }
    }
  }
}

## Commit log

2025-10-29 Revise README with new sections and links
    Updated the README to include new sections on mechanical, assembly, hardware setup, PCB, and firmware, along with relevant links.
2026-06-30 Add 3D-printable parts for Z-rotation policy deployment
    Add the STEP source files needed to 3D-print the hardware used when
    deploying the Z-rotation policy on the physical Aero Hand Open:
    - 60_60_60_block.stp: 60x60x60 mm cube the policy rotates about Z
    - mount.stp: fixture that holds the hand during deployment
    Document both files in the package README under a new
    "3D-Printed Hardware" section.
    [60_60_60_block.stp, mount.stp]
2026-06-30 Document ideal printed weight of the rotation block
    State that 60_60_60_block.stp should ideally be printed to weigh 117 g
    so the physical cube matches the mass the policy was trained against.
2026-07-28 assembly instructions (#50)
2026-09-11 Add arXiv paper link and citation to README (#54)
    The work is now published as arXiv:2608.28578 ("Aero Hand Open: A
    Simulation-Ready Tendon-Driven Hand for Dexterous Manipulation
    Learning"). Adds an arXiv badge, a Paper quick-link, and a Citation
    section with the BibTeX entry.
2026-09-11 Rebrand TetherIA → Chestnut Robotics; move links to the chestnut-robotics org (#55)
    TetherIA, Inc. is now Chestnut Robotics, Inc. (same legal entity, renamed).
    - Repository, org, project-page and raw-asset URLs → github.com/chestnut-robotics
    - Company site → https://chestnut.bot; mailboxes → the same names @chestnut.bot
    - Copyright / NOTICE lines → Chestnut Robotics, Inc. (formerly TetherIA, Inc.);
    per-file headers → Chestnut Robotics, Inc.
    - LICENSE.md: name-change note, attribution and trademark wording
    - Logo assets (sdk/assets, firmware/main/assets) → Chestnut Robotics wordmark
    - Fix Discussions/Issues badges that pointed at RoboVerseOrg/RoboVerse
    - SDK metadata GitHub UR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
    [Aero-Hand-Open-Left.kicad_sch, Aero-Hand-Open-Right.kicad_sch]
2026-09-15 Add manual servo offset calibration for tendon setup variations (#49)
    * Add manual actuator midpoint calibration
    * Add right-hand calibration firmware

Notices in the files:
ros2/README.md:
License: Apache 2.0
